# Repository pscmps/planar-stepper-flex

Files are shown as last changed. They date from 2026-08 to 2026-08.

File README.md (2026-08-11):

# Planar Stepper Flex

プリント配線をモータ巻線として使うXY平面ステッパの試作一式です。Pico 2 W、秋月電子の`AE-DRV8835-S` 4個、2種類の2層FPCを対象にしています。

> 現在は非公開で検証中です。回路・FPC・ファームウェアはいずれも試作品で、連続電流定格を保証していません。

## 収録内容

| ディレクトリ | 内容 |
|---|---|
| `hardware/pico2w-drv8835-controller/` | Pico 2 WとDRV8835 4個を載せる制御基板 |
| `hardware/drv8835-driver-module/` | 外部マイコン用DRV8835 4個基板 |
| `hardware/flex-50mm/` | 有効配線領域50 x 50 mmのFPC |
| `hardware/flex-4cards/` | 名刺4枚相当の有効配線領域を持つFPC。手描きシルク入り |
| `firmware/pico2-drv8835/` | USB G-code版、診断版、Pico 2 W Wi-Fi版 |
| `generator/` | 寸法指定可能なFPC生成器と手描きシルク注入処理 |
| `manufacturing/v0.1.0/` | DRC確認済みGerber ZIP、BOM、表裏PNG、ハッシュ |

## 基板プレビュー

| Pico 2 W制御基板 | DRV8835単独基板 |
|---|---|
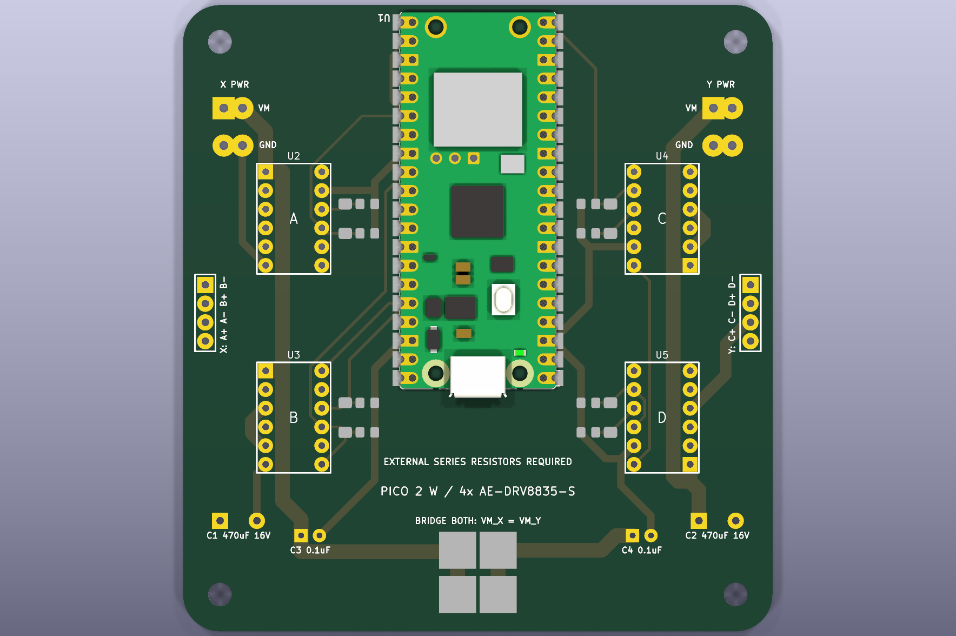
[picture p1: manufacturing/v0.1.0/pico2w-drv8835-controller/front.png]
Pico 2 W制御基板
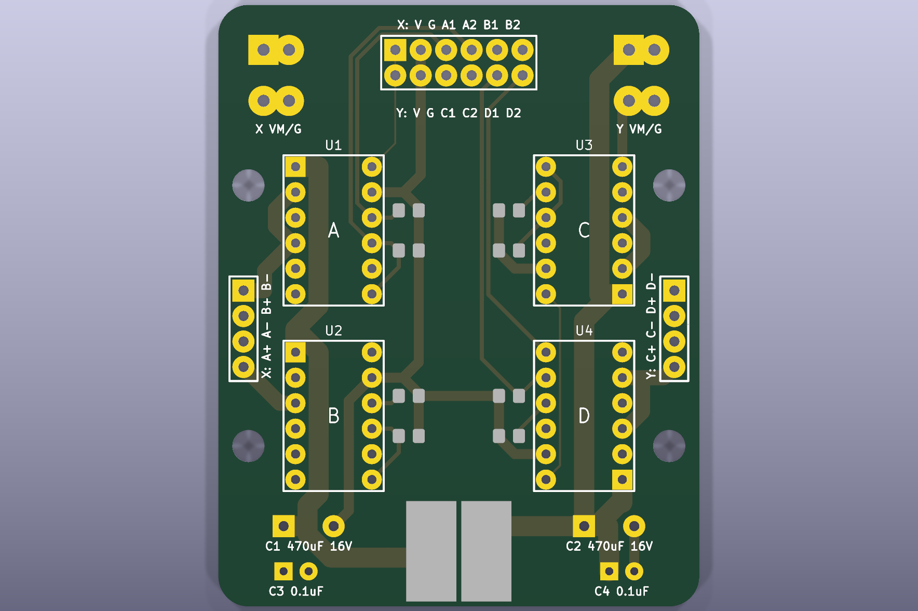
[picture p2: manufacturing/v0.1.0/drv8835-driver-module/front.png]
DRV8835単独基板
|  |  |

| 50 mm FPC | 名刺4枚サイズFPC |
|---|---|
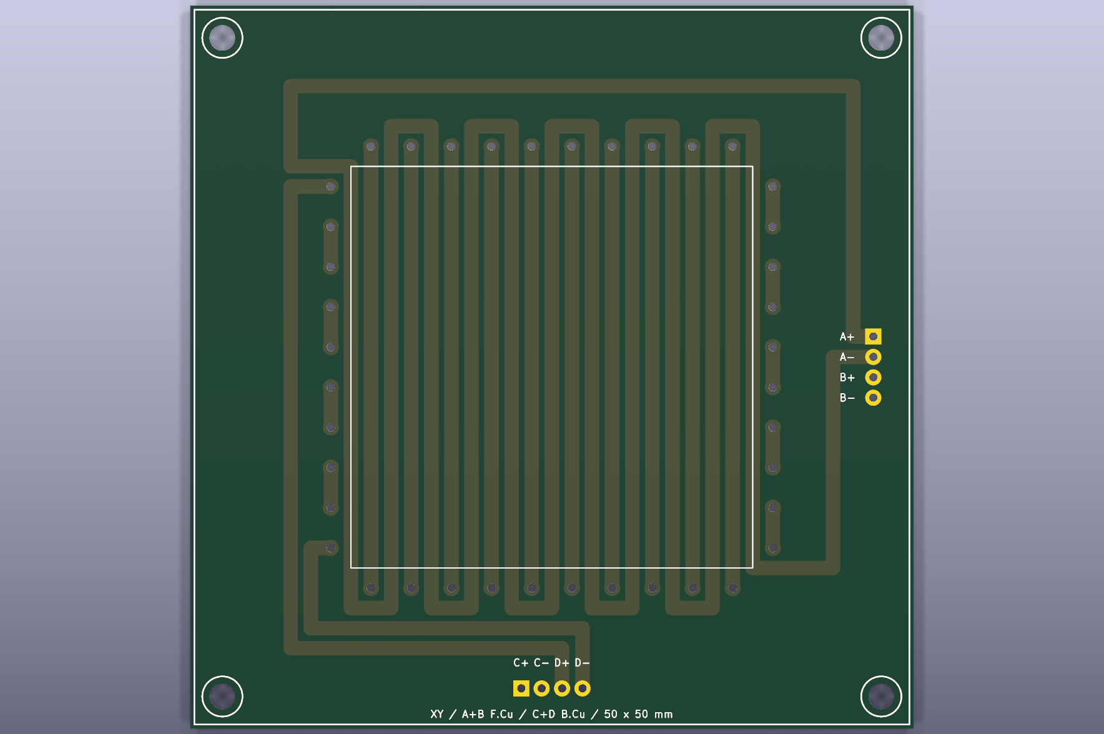
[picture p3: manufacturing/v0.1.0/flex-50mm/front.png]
50 mm FPC
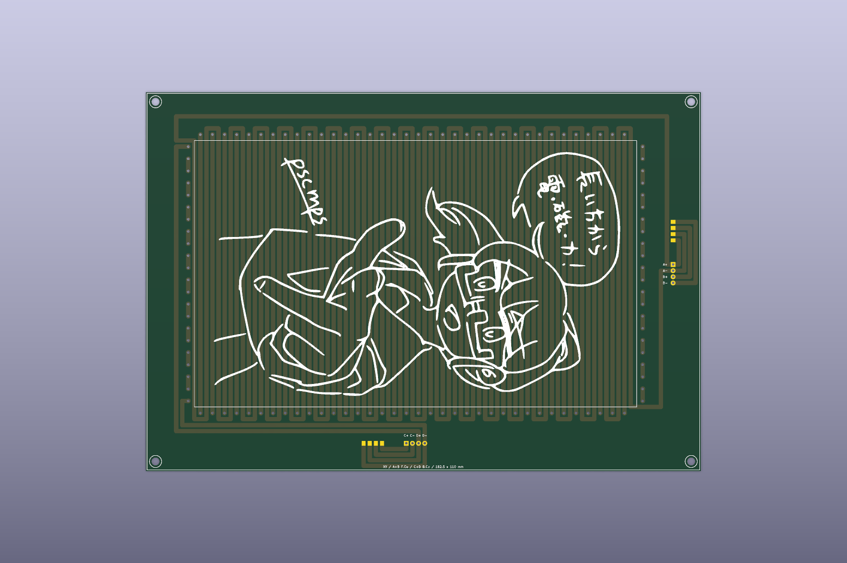
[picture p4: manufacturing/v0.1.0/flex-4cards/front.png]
名刺4枚サイズFPC
|  |  |

背面画像は各`manufacturing/v0.1.0/<board>/back.png`にあります。

## 最短手順

1. [安全上の注意](docs/safety.md)と[配線表](docs/wiring.md)を確認します。
2. VMを切った状態でPicoを起動し、DRV8835入力がLowであることを確認します。
3. 外付け直列抵抗と安定化電源の電流制限を使い、低い電圧・短い励磁から試します。
4. ファームウェアは[ビルド手順](docs/firmware-build.md)に従って生成します。
5. 基板を変更した場合は[製造データ手順](docs/manufacturing.md)でDRCとZIPを再生成します。

FPC生成器の使い方は[基板生成](docs/board-generation.md)、設計元と参考資料は[参考資料](docs/references.md)を参照してください。

## ライセンス

このリポジトリは複数ライセンスです。

| 対象 | ライセンス |
|---|---|
| ハードウェア設計、FPC、KiCadデータ、Gerberなど | [CERN-OHL-P-2.0](LICENSES/CERN-OHL-P-2.0.txt) |
| ファームウェア、生成器、プロジェクト独自ソフトウェア | [MIT](LICENSES/MIT.txt) |
| README、文書、プロジェクト独自の説明画像 | [CC BY 4.0](LICENSES/CC-BY-4.0.txt) |

第三者由来のコード、フットプリント、ライブラリには元のライセンスが適用されます。適用範囲と例外は[ライセンスと権利](RIGHTS.md)、第三者依存は[第三者通知](THIRD_PARTY_NOTICES.md)を参照してください。

## 使用報告は任意です

この設計を使って何か作った場合、作品や写真を教えていただけると嬉しいです。使用報告や連絡は必須ではありません。

If you build, modify, or incorporate this design into a project, the author would be happy to hear about it and see photos of your work. Reporting your use or contacting the author is entirely optional.

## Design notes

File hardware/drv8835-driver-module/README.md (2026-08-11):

# AE-DRV8835-S単独ドライバ基板

外部マイコンからA/B/C/D相を制御する、`AE-DRV8835-S` 4個の2層基板です。

- 外形: 48 x 60 mm、角R3 mm
- 入力J1: 上段X=`VCC GND A1 A2 B1 B2`、下段Y=`VCC GND C1 C2 D1 D2`
- X出力J4: `A+ / A- / B+ / B-`
- Y出力J5: `C+ / C- / D+ / D-`
- 固定穴: φ3.2 mm NPTH 4個

前面

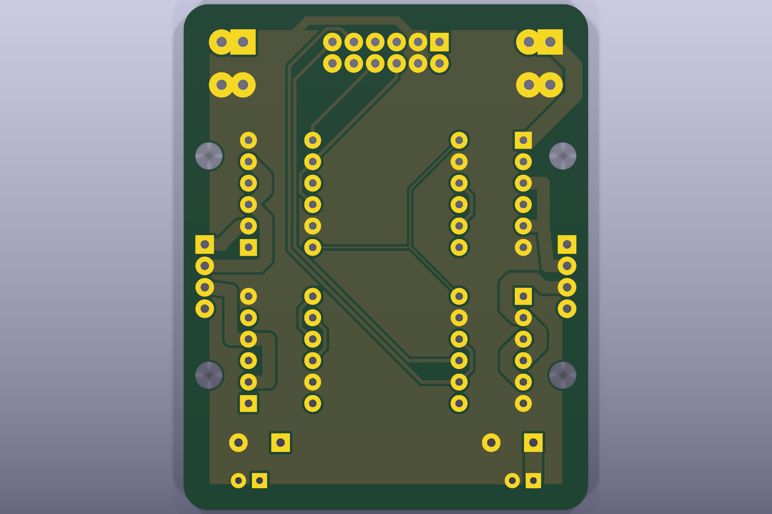
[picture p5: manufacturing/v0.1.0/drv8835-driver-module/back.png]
背面


入力`A1/A2`などはモータ出力名ではなく、対応する相モジュールの`IN1/IN2`です。各入力には10 kohmプルダウンがあります。VM_X/VM_Yは通常分離し、共通化する場合はVMはんだジャンパを両方閉じます。

製造ZIP、BOM、DRCレポートは[`../../manufacturing/v0.1.0/drv8835-driver-module/`](../../manufacturing/v0.1.0/drv8835-driver-module/)にあります。

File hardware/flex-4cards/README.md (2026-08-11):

# 名刺4枚サイズXY平面ステッパーFPC

標準名刺91 x 55 mmを2 x 2で並べた範囲を有効配線領域とする大型2層FPCです。

- 外形: 229.0 x 156.5 mm
- 有効配線領域: 182.5 x 110.0 mm
- ピッチ: 5.0 mm
- B/D相オフセット: 2.5 mm
- 配線幅: 1.8 mm
- 補助SMD端子: 表裏に各4極、既存PTH列から長手方向へ10 mm離して配置
- 手描きシルク: 生成時に`generator/assets/hand-drawn-silkscreen.kicad_mod`から追加

前面

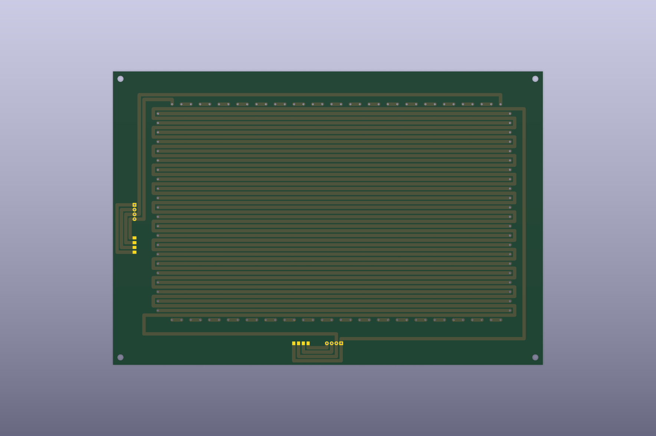
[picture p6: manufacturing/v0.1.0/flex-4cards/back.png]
背面


概算配線長と抵抗はA=4967.5 mm/1.359 ohm、B=4665.1 mm/1.277 ohm、C=4887.5 mm/1.337 ohm、D=4577.6 mm/1.253 ohmです。銅厚35 um、銅抵抗率1.724e-8 ohm mによる一次概算です。

このPCBは直接編集せず、[`../../docs/board-generation.md`](../../docs/board-generation.md)の`--preset 4cards --with-art`で再生成します。製造ZIPは[`../../manufacturing/v0.1.0/flex-4cards/`](../../manufacturing/v0.1.0/flex-4cards/)にあります。

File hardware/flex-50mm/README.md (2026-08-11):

# 50 mm XY平面ステッパーFPC

有効配線領域50 x 50 mmの2層FPCです。A/B相とC/D相を5 mmピッチ、2.5 mmオフセットで交互配置します。

前面

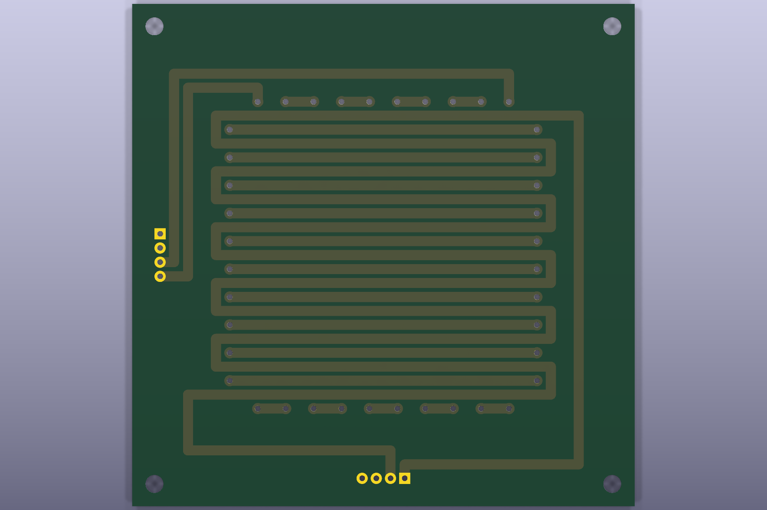
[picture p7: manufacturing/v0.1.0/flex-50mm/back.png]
背面


このPCBは直接編集せず、[`../../docs/board-generation.md`](../../docs/board-generation.md)の`--preset 50mm`で再生成します。製造ZIPは[`../../manufacturing/v0.1.0/flex-50mm/`](../../manufacturing/v0.1.0/flex-50mm/)にあります。

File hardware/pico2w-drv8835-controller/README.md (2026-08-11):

# Pico 2 W + AE-DRV8835-S制御基板

Pico 2 Wと`AE-DRV8835-S` 4個を載せ、A/B/C/D相を個別駆動する2層基板です。

- 外形: 80 x 85 mm、角R5 mm
- 相配線: 1.5 mm
- VM配線: 2.0 mm、X/Y別系統
- モジュール: 2.54 mm、列間7.62 mm、1相につき1個
- X出力: `A+ / A- / B+ / B-`
- Y出力: `C+ / C- / D+ / D-`

前面

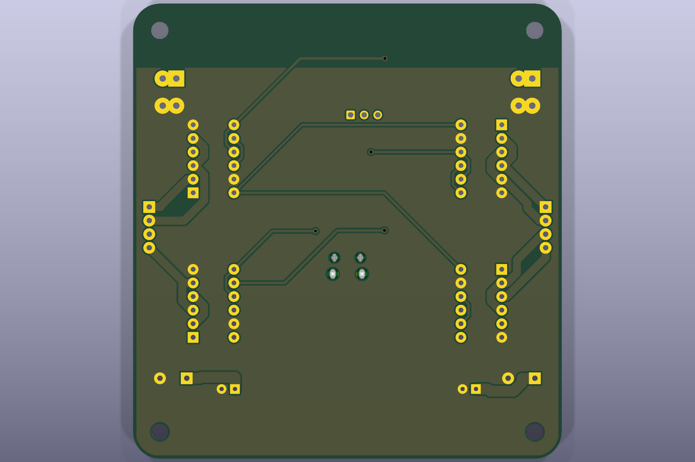
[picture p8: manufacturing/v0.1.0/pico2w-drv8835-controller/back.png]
背面


GPIO、AS5600、サーボ、将来microSDの割当は[`../../docs/wiring.md`](../../docs/wiring.md)を参照してください。VM_X/VM_Yを共通化する場合は両方のVMはんだジャンパを閉じ、電源入力は片側だけを使います。

製造ZIP、BOM、DRCレポートは[`../../manufacturing/v0.1.0/pico2w-drv8835-controller/`](../../manufacturing/v0.1.0/pico2w-drv8835-controller/)にあります。

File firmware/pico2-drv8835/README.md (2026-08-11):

# Pico 2 / Pico 2 W DRV8835 G-codeファームウェア

4個の`AE-DRV8835-S`で平面コイルのA/B/C/D相を駆動し、USBシリアルまたはPico 2 W内蔵Web UIから操作します。TMC2209用ターゲットはこの公開準備リポジトリに含めません。

## ターゲット

| ターゲット | 出力UF2 | 用途 |
|---|---|---|
| `pico2_gcode_drv8835_xy` | `pico2_gcode_drv8835_xy.uf2` | USB G-code通常運転 |
| `pico2_gcode_drv8835_xy_test` | `pico2_gcode_drv8835_xy_test.uf2` | 相単独励磁とGPIO診断 |
| `pico2w_gcode_drv8835_wifi` | `pico2w_gcode_drv8835_wifi.uf2` | USB G-code + Wi-Fi APジョグ |

ビルドはリポジトリ直下の`scripts/build-firmware.ps1`を使います。

## 対応指令

- `G0/G1 X... Y... Z... F...`
- `G2/G3`は未対応。PlotterFlow側で線分化します。
- `G20/G21`、`G90/G91`、`G92`、`G10 L20 P0`
- `$J=G91 G21 X... Y... F...`
- `M17/M18`、`M3/M5`、`M281`、`M980`、`M982`、`M983`
- `?`、`!`、`~`、ジョグキャンセル`0x85`

通常移動は汎用G-codeだけで行います。独自命令は起動時設定と診断に限定します。

## DRV8835設定 M980

```gcode
M18
M980 U8 X60 Y60 I100 J100 H500 C100 B8 R16 A1
M17
```

| 引数 | 意味 |
|---|---|
| `U` | 1フル状態の分割数。`1/2/4/8/16` |
| `X/Y` | X/Y通常PWM、1～100% |
| `I/J` | X/Y初動PWM、1～100% |
| `H` | 移動終了後の保持時間、0～5000 ms |
| `C` | Hi-Z解除時の捕捉時間、0～500 ms |
| `B` | 初動PWMを維持する各軸マイクロステップ数 |
| `R` | 通常PWMへ線形復帰する各軸マイクロステップ数 |
| `A1` | 移動中の軸だけ励磁。`A0`は両軸保持 |

設定後は`G0/G1`と`$J`へ自動適用され、移動ごとに`M980`を送る必要はありません。`B0 R0`は初動ブーストなしの従来動作です。出力OFF、保持終了、新しい軸の励磁開始時にブーストし、保持中の同軸連続G1では再開始しません。

確実な1相励磁を優先する場合は次を使います。

```gcode
M18
M980 U1 X100 Y100 I100 J100 H500 C100 B0 R0 A1
M17
```

## Zサーボ

GP12から50 Hz PWMを出力します。既定はペンアップ1000 us、ペンダウン1800 usです。

```gcode
M281 P0 S1000   ; Up
M281 P1 S1800   ; Down
G0 Z1           ; Up
G0 Z0           ; Down
```

## 任意センサ

- GP26/ADC0: 電流センサ。`M982`で確認。未接続でも運転を継続します。
- AS5600 J1: I2C0、GP8 SDA、GP9 SCL
- AS5600 J2: I2C1、GP10 SDA、GP11 SCL
- `M983`: 1回読出し、`M983 S1/S0`: 状態応答への連続掲載ON/OFF

AS5600が片方または両方なくてもエラー停止しません。詳細な配線は[`../../docs/wiring.md`](../../docs/wiring.md)を参照してください。

## Wi-Fi版

- SSID: `PlanarStepper-XXXX`
- パスワード: `planar-stepper`
- URL: `http://192.168.4.1/`

Pico 2 W自身がAP、DHCP、Web UIを提供します。接続手順とAPIは[`docs/pico2w_wifi_jog.md`](docs/pico2w_wifi_jog.md)にあります。

## 書き込み

BOOTSELを使わず、USBシリアルから同じPicoを特定してpicotoolで再起動・書き込みできます。

```powershell
powershell -ExecutionPolicy Bypass -File tools\flash_wifi.ps1 -Port COM6 -Picotool D:\path\to\picotool.exe -Uf2 D:\path\to\pico2w_gcode_drv8835_wifi.uf2
```

書き込み中はVMとサーボ電源を切ってください。USBデバイスが列挙されない場合はBOOTSEL書き込みが必要です。

## 実機確認

[`docs/drv8835_gcode_bringup.md`](docs/drv8835_gcode_bringup.md)の順に、VM OFFでGPIO Low、低電圧・電流制限、X、Y、XY、停止を確認します。

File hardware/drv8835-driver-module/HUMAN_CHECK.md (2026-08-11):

# 単独ドライバ基板の人間確認手順

1. 外形48 x 60 mm、角R3 mm、φ3.2 mm固定穴4個を確認する。
2. J1上段が`VCC GND A1 A2 B1 B2`、下段が`VCC GND C1 C2 D1 D2`であることを確認する。
3. J4が`A+ A- B+ B-`、J5が`C+ C- D+ D-`であることを確認する。
4. AE-DRV8835-Sの2.54 mmピッチ、列間7.62 mm、向きを実物で確認する。
5. VM_XとVM_Yがジャンパ開放時に絶縁され、GNDは共通であることを確認する。
6. [`../../manufacturing/v0.1.0/drv8835-driver-module/drc.rpt`](../../manufacturing/v0.1.0/drv8835-driver-module/drc.rpt)が違反0、未配線0であることを確認する。
7. VM OFFで全入力のプルダウンと出力端子間の短絡がないことを確認する。
8. 直列抵抗と電流制限を使い、1相ずつ短時間通電する。

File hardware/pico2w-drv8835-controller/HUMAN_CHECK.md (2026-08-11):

# 制御基板の人間確認手順

1. 外形80 x 85 mm、角R5 mm、固定穴、Pico 2 Wと4モジュールの向きを実物へ重ねて確認する。
2. X出力が`A+ A- B+ B-`、Y出力が`C+ C- D+ D-`の順であることを確認する。
3. VM_XとVM_Yがジャンパ開放時に絶縁され、GNDは共通であることをテスターで確認する。
4. VM-GND、3.3V-GND、異なる相出力間に短絡がないことを確認する。
5. 電解コンデンサ、Pico 2 W、AE-DRV8835-Sの向きを確認する。
6. [`../../manufacturing/v0.1.0/pico2w-drv8835-controller/drc.rpt`](../../manufacturing/v0.1.0/pico2w-drv8835-controller/drc.rpt)が違反0、未配線0であることを確認する。
7. 製造業者のGerberビューアで銅箔、マスク、シルク、PTH/NPTHを確認する。
8. VM OFFでPicoを起動し、GP15～GP22と全DRV8835入力がLowであることを確認する。
9. 各相へ直列抵抗を入れ、低電圧・電流制限からX、Yの順に通電する。

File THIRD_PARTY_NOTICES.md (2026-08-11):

# 第三者通知

プロジェクト独自のライセンスは、次の第三者成果物を上書きしません。ソース内の著作権表示とライセンスヘッダーは変更せず維持しています。

## リポジトリへ直接収録しているもの

| 成果物 | 収録場所 | 収録ファイルの著作権・ライセンス | 正式本文と由来 |
|---|---|---|---|
| MicroPython由来DHCP server | `firmware/pico2-drv8835/third_party/pico_examples/dhcpserver.c/.h` | ファイルヘッダーはCopyright (c) 2018-2019 Damien P. George、MIT | pico-examplesの当該ディレクトリに付属するLICENSE（Copyright (c) 2013-2022 Damien P. George）を[LicenseRef-MicroPython-MIT.txt](LICENSES/LicenseRef-MicroPython-MIT.txt)へ原文のまま収録 |
| Raspberry Pi Pico examples DNS server | `firmware/pico2-drv8835/third_party/pico_examples/dnsserver.c/.h` | ファイルヘッダーはCopyright (c) 2022 Raspberry Pi (Trading) Ltd.、`BSD-3-Clause` | pico-examplesルートのLICENSE.TXT（Copyright 2020 (c) 2020 Raspberry Pi (Trading) Ltd.）を[BSD-3-Clause.txt](LICENSES/BSD-3-Clause.txt)へ原文のまま収録 |
| KiCad公式Pico Wフットプリント | `hardware/pico2w-drv8835-controller/footprints/official-kicad/` | KiCad library contributors、CC BY-SA 4.0とKiCad libraries exception | KiCad公式`LICENSE.md`を[LicenseRef-KiCad-Libraries.txt](LICENSES/LicenseRef-KiCad-Libraries.txt)へ原文のまま収録 |

DHCP/DNSの派生元は、Raspberry Pi公式pico-examplesのコミット`eed0c298202ddbdc3aadb386abedb71ae528e5fb`です。DHCP付属LICENSEはコミット`1c5d9aa567598e6e3eadf6d7f2d8a9342b44dab4`、pico-examplesルートLICENSE.TXTはコミット`46078742c7f8dea8b5a0998c73b38ff970fb1b64`の原文を確認しました。収録DHCPコードには再接続時の要求IP補完、ホスト名・送受信診断ログ、初期化結果の返却を追加しています。DNSコードの差分は未使用引数警告の抑制です。元の著作権・ライセンスヘッダーは変更していません。

`BSD-3-Clause.txt`とPico SDK付属LICENSEの冒頭にある`Copyright 2020 (c) 2020 Raspberry Pi (Trading) Ltd.`は、年が重複して見えますがRaspberry Pi公式原文の表記です。このリポジトリでは訂正せず、一字一句そのまま収録しています。

KiCadフットプリントは、公式コミット`18227ee1af2680cab46c6ed908dd53e9272a6116`の同名ファイルと比較し、2個のkeep-out zoneから`F.Paste`と`B.Paste`を除いた差分だけであることを確認しました。詳細は同ディレクトリの`NOTICE`を参照してください。

KiCadフットプリントの形状はRaspberry Pi Pico W/Pico 2 W公式寸法資料を参照しています。Raspberry Piの名称、商標、データシート、製品設計に対する権利は各権利者に帰属し、このリポジトリのライセンス対象ではありません。

## ビルド依存と配布UF2

次の依存物はリポジトリへソースを複製していませんが、Pico SDKを通してファームウェアのビルドまたは配布UF2へ組み込まれます。

| 依存物 | 確認したリビジョン | 著作権・ライセンス | 依存元から複製した本文 |
|---|---|---|---|
| Raspberry Pi Pico SDK | `a1438dff1d38bd9c65dbd693f0e5db4b9ae91779` | Copyright 2020 (c) 2020 Raspberry Pi (Trading) Ltd.、BSD-3-Clause | [LicenseRef-Raspberry-Pi-Pico-SDK-BSD-3-Clause.txt](LICENSES/LicenseRef-Raspberry-Pi-Pico-SDK-BSD-3-Clause.txt) |
| lwIP | `77dcd25a72509eb83f72b033d219b1d40cd8eb95` | Copyright (c) 2001, 2002 Swedish Institute of Computer Science、BSD系3条項 | [LicenseRef-lwIP-BSD-3-Clause.txt](LICENSES/LicenseRef-lwIP-BSD-3-Clause.txt) |
| TinyUSB | `86ad6e56c1700e85f1c5678607a762cfe3aa2f47` | Copyright (c) 2018, hathach (tinyusb.org)、MIT | [LicenseRef-TinyUSB-MIT.txt](LICENSES/LicenseRef-TinyUSB-MIT.txt) |
| cyw43-driver | `dd7568229f3bf7a37737b9e1ef250c26efe75b23` | Copyright (C) 2019-2022 George Robotics Pty Ltd、Raspberry Pi製半導体との組み合わせに限定した許諾 | [LicenseRef-CYW43-Raspberry-Pi.txt](LICENSES/LicenseRef-CYW43-Raspberry-Pi.txt) |

`manufacturing/v0.1.0/firmware/`のUF2を再配布する場合も、この第三者通知と該当ライセンス本文を一緒に提供してください。実際にリンクされるコンポーネントはPico SDKのバージョンとCMake設定に依存します。特にWi-Fi版UF2の`cyw43-driver`は、Pico 2 Wを含むRaspberry Pi Ltd製半導体と組み合わせて使用・再配布する場合に限られます。

## KiCad標準ライブラリを使った設計

KiCad標準ライブラリはCC BY-SA 4.0にKiCad libraries exceptionを加えた条件です。この例外は、ライブラリデータを使って作成した回路・基板設計や生成ファイルを別ライセンスで提供することを認めています。そのため、このプロジェクト独自の基板設計とGerberにはCERN-OHL-P-2.0を適用します。再配布するKiCadライブラリ要素そのものには元のライセンスを維持します。

## 外部リンク

READMEや`docs/references.md`から参照する外部記事、データシート、Webサイトの内容や画像は、このリポジトリのライセンス対象ではありません。現時点で第三者記事の画像や本文はリポジトリへ転載していません。

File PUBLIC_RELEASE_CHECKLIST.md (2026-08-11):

# 公開前チェックリスト

- [x] ハードウェアを`CERN-OHL-P-2.0`に決定した
- [x] プロジェクト独自ソフトウェアを`MIT`に決定した
- [x] プロジェクト独自文書・画像を`CC-BY-4.0`に決定した
- [x] `LICENSES/`へ正式本文と第三者ライセンス通知を収録した
- [x] `LICENSES/`からSPDXテンプレート変数と未展開プレースホルダーを除去した
- [x] Pico SDK、lwIP、TinyUSB、cyw43-driver、pico-examples、KiCadの実依存元と本文を照合した
- [x] `REUSE.toml`と`RIGHTS.md`へ適用範囲と例外を記載した
- [x] 第三者ソースの著作権・ライセンスヘッダーを維持した
- [ ] リポジトリをprivateのまま最終レビューした
- [ ] 個人情報、Wi-Fi資格情報、Webhook、絶対パスを除去した
- [ ] 4基板のDRCが違反0、未配線0であることを再確認した
- [ ] Gerber ZIPとUF2のSHA-256を再検証した
- [ ] BOMと実装品の型番・向きを照合した
- [ ] 実機の電流制限、発熱、サーボ方向、非常停止を再確認した
- [ ] READMEの画像とリンクをGitHub上で確認した
- [ ] privateからpublicへ変更する直前のコミットへタグを付けた
- [ ] GitHubのvisibilityをpublicへ変更した

使用報告は任意です。公開条件やライセンス条件として要求しません。

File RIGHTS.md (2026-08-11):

# ライセンスと権利

Planar Stepper Flexは、成果物の種類に応じた複数ライセンスで提供します。Copyright (c) 2026 pscmps.

## ハードウェア設計

プロジェクト独自のハードウェア設計は[CERN Open Hardware Licence Version 2 - Permissive](LICENSES/CERN-OHL-P-2.0.txt)、SPDX識別子`CERN-OHL-P-2.0`で提供します。

対象:

- `hardware/`以下の`.kicad_pcb`、`.kicad_pro`、配線マニフェスト、BOMなどの設計データ
- `generator/assets/hand-drawn-silkscreen.kicad_mod`
- FPC、回路、PCB、Gerber、ドリル、製造ZIPなど、それらから生成されたハードウェア設計データ

製造、改造、再配布、商用利用が可能です。CERN-OHL-P-2.0はpermissive版であり、改造設計を同じライセンスで公開することを要求しません。ただし、ライセンス本文が定めるNotice保持、変更表示、製品受領者からNoticeへアクセスできる状態などの条件は守ってください。

## ソフトウェア

プロジェクト独自のソフトウェアは[MIT License](LICENSES/MIT.txt)、SPDX識別子`MIT`で提供します。

対象:

- `firmware/`のプロジェクト独自ソース、Web UI、ツール、テスト、G-code例
- `generator/`のPythonコード。ただしハードウェア設計アセットは前項
- `hardware/`内の基板生成・自動配線Pythonスクリプト
- `scripts/`とその他のプロジェクト独自ソフトウェア

`firmware/pico2-drv8835/third_party/`などの第三者コードには元のライセンスが適用され、プロジェクトのMIT Licenseで上書きしません。UF2はプロジェクト独自MITコードと第三者コンポーネントを含む複合物です。

## 文書と画像

プロジェクト独自の文書と説明画像は[Creative Commons Attribution 4.0 International](LICENSES/CC-BY-4.0.txt)、SPDX識別子`CC-BY-4.0`で提供します。

対象:

- `README.md`、`AGENTS.md`、`PUBLIC_RELEASE_CHECKLIST.md`、`docs/`
- 各サブディレクトリのREADME、確認手順、説明文書
- プロジェクトで新規作成したPNG、SVG、基板プレビュー、説明図

推奨する表示例は「Planar Stepper Flex by pscmps, CC BY 4.0, https://github.com/pscmps/planar-stepper-flex」です。これはCC BY 4.0の表示を分かりやすくする例であり、ライセンスが要求する範囲を超える追加条件ではありません。

## 第三者成果物と例外

第三者由来のコード、ライブラリ、フットプリント、資料、画像、商標には上記のプロジェクトライセンスを適用しません。[第三者通知](THIRD_PARTY_NOTICES.md)と各ソース内の著作権・SPDXヘッダーを優先してください。

特に、KiCad公式ライブラリ由来フットプリントはCC BY-SA 4.0とKiCad libraries exceptionの組み合わせです。KiCadの例外により、そのライブラリ要素を使って作成した基板設計と生成ファイルへCERN-OHL-P-2.0を適用できますが、収録したフットプリント単体はKiCad側の条件を維持します。`REUSE.toml`では、この組み合わせを`LicenseRef-KiCad-Libraries`として表します。

Pico 2 W Wi-Fi版UF2に含まれる`cyw43-driver`は`LicenseRef-CYW43-Raspberry-Pi`です。Raspberry Pi Ltd製のRP2040、RP2350その他同社製半導体との組み合わせに限定して利用・再配布できます。この制約はWi-Fiバイナリ内の第三者部分に由来し、プロジェクト独自ソースのMIT Licenseを変更するものではありません。

正式な対応表は[`REUSE.toml`](REUSE.toml)にも記載しています。第三者ファイルを含め、対象ごとの情報を`precedence = "override"`で一意にしています。ソース内の著作権・ライセンス表示も維持しています。

## ライセンス本文の出典

- `CERN-OHL-P-2.0.txt`: Open Hardware Repositoryが配布する`cern_ohl_p_v2.txt`の原文
- `CC-BY-4.0.txt`: Creative Commons公式`https://creativecommons.org/licenses/by/4.0/legalcode.txt`の原文
- `MIT.txt`: 標準MIT本文へ、このプロジェクトの実際の表示`Copyright (c) 2026 pscmps`を記載
- 第三者ライセンス: [第三者通知](THIRD_PARTY_NOTICES.md)に記録した各依存元の付属ファイルから複製

`LICENSES/`にはSPDXテンプレート用の`<<var;...>>`、`<<beginOptional...>>`、`<year>`などを含めません。監査済み原文の改変とプレースホルダー再混入は`scripts/check-license-scope.py`で検出します。

## 使用報告

この設計を使って何か作った場合、作品や写真を教えていただけると嬉しいです。使用報告や連絡は必須ではありません。

If you build, modify, or incorporate this design into a project, the author would be happy to hear about it and see photos of your work. Reporting your use or contacting the author is entirely optional.

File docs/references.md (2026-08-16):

# 参考資料

- [Research log: PCB stepper motor](https://kevinlynagh.com/pcb-stepper/)
- [Hackaday: The Two-Dimensional Stepper Motor](https://hackaday.com/2019/05/09/the-two-dimensional-stepper-motor/)
- [Hackaday.io: 2D Stepper Motor Etched on PCB](https://hackaday.io/project/164507-2d-stepper-motor-etched-on-pcb-micro-manipulator)
- [秋月電子 AE-DRV8835-S商品ページ](https://akizukidenshi.com/catalog/g/g109848/)
- [秋月電子 AE-DRV8835-S説明書](https://akizukidenshi.com/goodsaffix/AE-DRV8835-S_20210526.pdf)
- [TI DRV8835データシート](https://www.ti.com/lit/ds/symlink/drv8835.pdf)
- [Raspberry Pi Pico 2 Wデータシート](https://datasheets.raspberrypi.com/picow/pico-2-w-datasheet.pdf)
- [Raspberry Pi Pico SDK](https://github.com/raspberrypi/pico-sdk)
- [KiCad 10 Documentation](https://docs.kicad.org/10.0/)
- [PlotterFlow Web](https://pscmps.github.io/plotterflow-web/)
- [PlotterFlow GitHub](https://github.com/pscmps/plotterflow-web)

参考設計と同じ性能や安全性を保証するものではありません。寸法、材料、駆動方式の差を考慮して評価してください。

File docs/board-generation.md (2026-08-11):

# FPC基板生成

## プリセット生成

KiCad 10付属Pythonを使います。

```powershell
D:\kicad10\bin\python.exe generator\generate_flex_board.py --preset 50mm --output hardware\flex-50mm\one_axis_stepper.kicad_pcb
D:\kicad10\bin\python.exe generator\generate_flex_board.py --preset 4cards --with-art --output hardware\flex-4cards\planar_stepper_flex_4cards.kicad_pcb
```

`--with-art`は名刺4枚プリセットへだけ指定できます。手描きシルクは`generator/assets/hand-drawn-silkscreen.kicad_mod`から注入されます。

## 任意寸法

```powershell
D:\kicad10\bin\python.exe generator\generate_flex_board.py --preset 50mm --active-width 100 --active-height 80 --output build\flex-100x80.kicad_pcb
```

有効配線領域を指定し、外形を省略した場合は折り返しと端子用に各方向40 mmを加えます。必要に応じて`--board-width`、`--board-height`、`--pitch`、`--trace-width`、`--spacing`、`--phase-offset`を指定できます。全オプションは`--help`で確認してください。

## 検証

```powershell
python -m unittest discover -s generator\tests -v
```

生成後は必ず`kicad-cli pcb drc`を実行してください。製造データまで一括生成する場合は`docs/manufacturing.md`を参照します。

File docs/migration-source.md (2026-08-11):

# 移行元

このリポジトリは`pscmps/kicad-10-one-axis-planar-stepper`から、公開対象をDRV8835方式へ限定して再構成しました。

- 取り込み基準コミット: `2f0866f`
- 名刺4枚版FPC: 移行時点の未コミット作業ツリーにあった手描きシルクと追加端子を含む版
- 移行後に再生成した名刺4枚版PCB SHA-256: `b0611244fdda0f6ffc602114e7ef7fc088943e93047a177f7a169f11e8145e2e`
- 除外: TMC2209、コイルマトリクス、M5Stack、Fusion治具、実験ログ

移行元リポジトリは変更していません。過去の検討履歴は移行元のGit履歴を参照してください。

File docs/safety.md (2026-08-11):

# 安全上の注意

- DRV8835にはTMC2209のような相電流設定機能がありません。直列抵抗、電源電流制限、PWM dutyで電流を制限します。
- 初回はVMを低くし、各相へ1.5 ohm・5 W以上の直列抵抗を入れ、短時間だけ励磁します。
- FPC配線は低抵抗です。電源を直接つなぐと過電流、発熱、銅箔損傷の危険があります。
- 初動ブースト100%は連続運転用ではありません。抵抗、DRV8835、コネクタ、FPCの温度を確認します。
- VM-GND間へ電解コンデンサを配置し、極性と耐圧を確認します。
- 配線変更、導通測定、Pico書き込みはVMとサーボ電源を切って行います。
- `M18`、停止、キャンセル後に8出力がLowとなることをVM投入前に確認します。
- 製造した基板は最初に電流制限付き安定化電源で確認し、無人運転しないでください。

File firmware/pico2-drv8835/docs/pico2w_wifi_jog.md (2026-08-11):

# Pico 2 W スマホWi-Fiジョグ手順

## 対象と制約

`pico2w_gcode_drv8835_wifi.uf2`は、Pico 2 W自身をWi-Fiアクセスポイントにして、スマホのブラウザからDRV8835版XY平面ステッパをジョグするファームです。既存のUSB G-codeと`M980`は残しています。

この機能は操作経路だけを追加します。現在検討中の電源容量、直列抵抗、コイル電流、磁力の問題は改善しません。実機試験では従来どおりVM 3 V、電源制限1.5 A、各相1.5 Ωから開始してください。

## GPIO配置

Wi-Fi版もUSB版DRV8835バックエンドと同じGPIOを使用します。起動処理の最初にGP15からGP22を出力Lowへ設定し、Wi-Fi初期化に失敗しても励磁しません。

| 軸・相 | DRV8835入力 | Pico 2 W GPIO |
|---|---|---:|
| X A相 | AIN1 / AIN2 | GP19 / GP20 |
| X B相 | BIN1 / BIN2 | GP21 / GP22 |
| Y C相 | AIN1 / AIN2 | GP15 / GP16 |
| Y D相 | BIN1 / BIN2 | GP17 / GP18 |
| Zサーボ | PWM信号 | GP12（物理16番） |

Pico 2 W、DRV8835、モーター電源、サーボ電源のGNDを共通にします。VMやサーボ電源をPico 2 Wの3V3端子から供給しないでください。サーボは外部5 Vから給電します。

## 接続

1. VMをOFFにしてPico 2 Wを起動します。
2. USBシリアルの起動ログで`WIFI AP`、SSID、URLを確認します。
3. スマホのWi-Fi設定で`PlanarStepper-XXXX`を選びます。
4. パスワード`planar-stepper`を入力します。
5. インターネット未接続の警告が出ても、このWi-Fi接続を維持します。
6. ブラウザで`http://192.168.4.1/`を開きます。

Pico自身のAP専用です。DNSと主要OSの接続確認URLに応答するため、対応端末では操作画面が自動表示されます。家庭内Wi-Fiへの参加、設定保存、インターネット中継は実装していません。

## 画面操作

| ボタン | G-code方向 |
|---|---|
| 上 | Yマイナス |
| 下 | Yプラス |
| 左 | Xプラス |
| 右 | Xマイナス |
| 中央の停止 | 移動キャンセル後、全出力Low |
| ペン上 | `G0 Z1`相当 |
| ペン下 | `G1 Z0`相当 |

駆動モードは、1相を100%励磁する「確実動作 U1」と、2相をsin/cos PWMする「滑らか動作 U8（実験）」から選択できます。既定は確実動作で、移動量は2.5 mmです。滑らか動作へ切り替えると0.625 mmを選択します。移動量は`0.3125 / 0.625 / 2.5 / 10 mm`から変更でき、Feedは30から1000 mm/min、初期値は300 mm/minです。

HTTP要求は1件だけキューへ入り、メインループで既存の`$J=G91 G21 ...`に変換されます。実行中は十字ボタンを無効にし、重複ジョグを受け付けません。中央停止は通信コールバックからプランナのキャンセルフラグを立て、移動ループが約1 ms周期で検出します。

## 内部API

```text
GET /api/jog.cgi?axis=X&direction=1&distance=0.625&feed=300
GET /api/stop.cgi
GET /api/mode.cgi?activeOnly=1&microsteps=1&captureMs=100
GET /api/pen.cgi?state=up
GET /api/pen.cgi?state=down
GET /api/status.shtml
```

`axis`は`X`または`Y`、`direction`は`-1`または`1`、移動量は画面にある4値だけ、Feedは30から1000の整数だけを受理します。不正入力はHTTP 400、実行中の追加要求は`busy`を返します。
`pen.cgi`は`state=up`または`state=down`だけを受理し、メインループで通常のZ G-codeへ変換します。

状態応答例:

```json
{"ready":true,"busy":false,"armed":true,"outputs":false,"activeOnly":true,"microsteps":1,"captureMs":100,"activeMask":0,"xAngle":0,"yAngle":0,"xPhase":"A+","yPhase":"C+","clients":1,"x":0.0000,"y":0.0000,"z":1.0000,"penPulseUs":1000,"penUp":true,"lastResult":"ok"}
```

`activeOnly=1`は移動する軸だけを励磁し、`activeOnly=0`は常にXY両軸を励磁します。`microsteps`は画面で使用する`1`または`8`、`captureMs`はHi-Z解除時と対象軸切替時の捕捉時間で、0から500msです。設定変更時は安全のため一度全出力をLowへ戻し、論理座標を維持したまま電気角を基準相へ同期します。

## 接続できない場合の判定

USBシリアルを115200 baudで開いたまま、スマホ側でネットワークを一度削除してから再接続します。

- `[WIFI AP: clients=0]`のまま: パスワード認証またはWi-Fi関連付けまで到達していません。
- `[WIFI AP: clients=1]`は出るが`DHCPS: client connected`が出ない: DHCP払い出し段階の問題です。
- `DHCPS: client connected`まで出る: IP取得済みです。ブラウザへ`http://192.168.4.1/`を直接入力します。

ファーム0.6.2以降は、スマホの初回DHCP要求だけでなく、要求IPオプションを省略する再接続・リース更新も受理します。インターネット未接続の警告では「このネットワークを使用」を選びます。IP取得済みなのに携帯回線へ迂回する場合だけ、確認中はモバイルデータ通信を一時的にOFFにします。

## 安全な実機確認

1. VMをOFFにし、起動直後からGP15からGP22がLowであることを確認します。
2. スマホからAPと操作画面を開き、座標と`出力 Hi-Z`が表示されることを確認します。
3. 十字ボタンを連打し、実行中に2件目が入らないことを確認します。
4. VM 3 V、電流制限1.5 A、各相1.5 Ωで、「確実動作 U1」、移動量2.5 mmからYを試します。
5. 次にX、最後にXYを交互に操作します。
6. 10 mmの低速ジョグ中に中央停止を押し、200 ms以内に停止して出力がLowへ戻ることを確認します。
7. 移動中にブラウザを閉じます。指定距離以上に継続せず、移動完了500 ms後に`出力 Hi-Z`になることを確認します。
8. USBから`M122`を送り、座標、armed状態、`single-phase`、`capture_ms=100`、現在相、対象軸、出力状態を照合します。

標準G-codeでの比較には次を使用します。

```gcode
M18
M980 U1 X100 Y100 H500 A1 C100
M17
G91
G1 X2.5 F300
G1 X-2.5 F300
G1 Y2.5 F300
G1 Y-2.5 F300
M18
```

回路の発熱、電源CC移行、異音、抵抗の過熱を検出した場合は、画面操作を続けずVMをOFFにします。

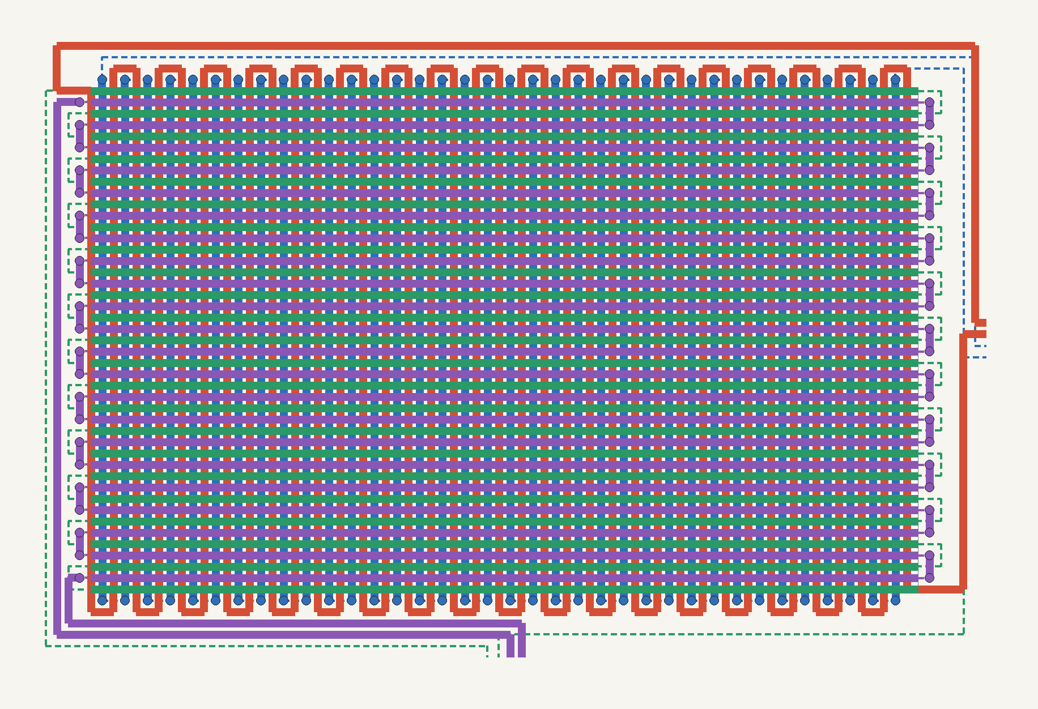
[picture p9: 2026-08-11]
hardware/flex-4cards/planar_stepper_flex_4cards_overlay.png

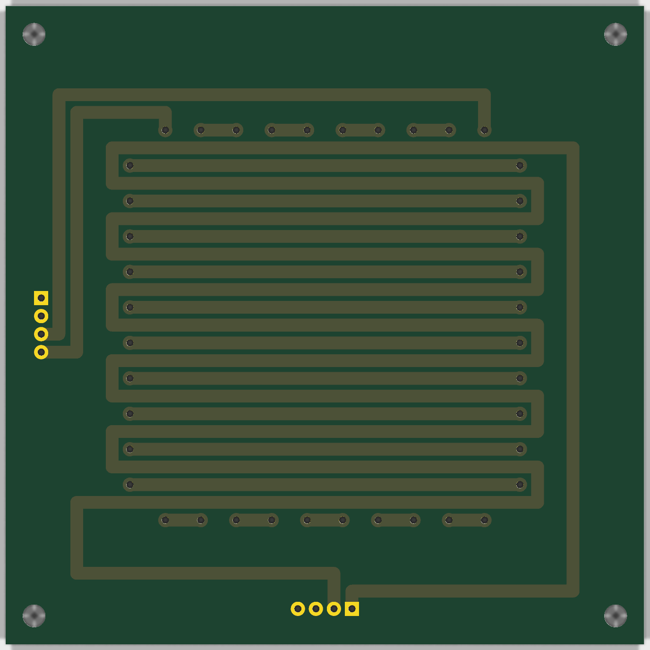
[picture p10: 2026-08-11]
hardware/flex-50mm/one_axis_stepper_bottom.png

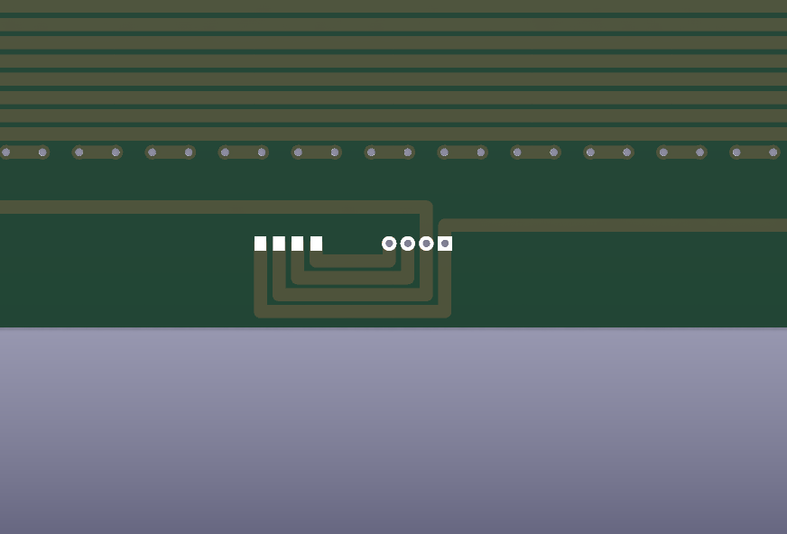
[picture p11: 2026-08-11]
hardware/flex-4cards/terminal_j2_back.png

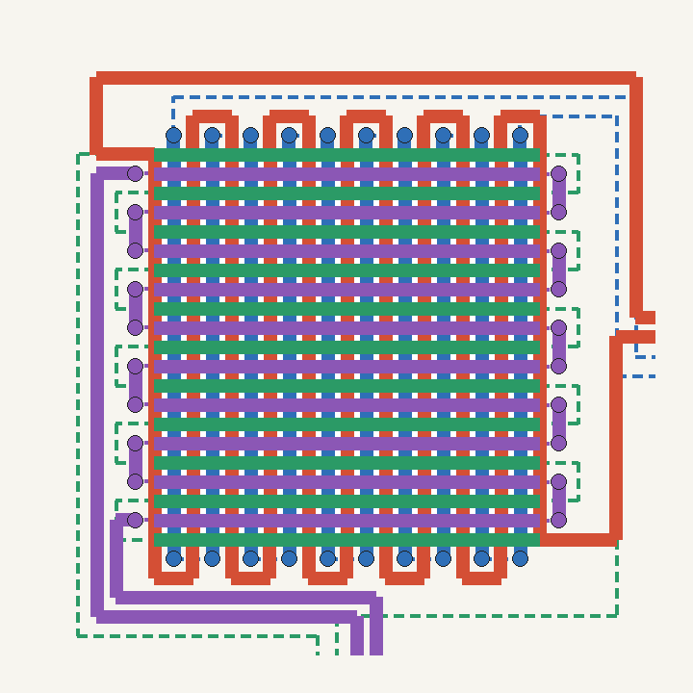
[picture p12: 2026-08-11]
hardware/flex-50mm/one_axis_stepper_single_layer_preview.png

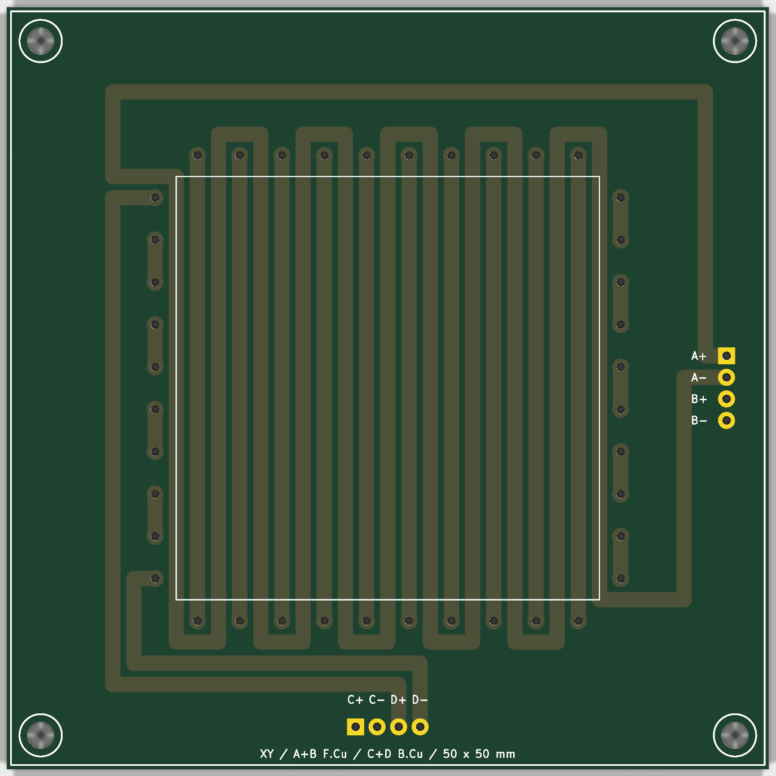
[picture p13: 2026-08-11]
hardware/flex-50mm/one_axis_stepper.png

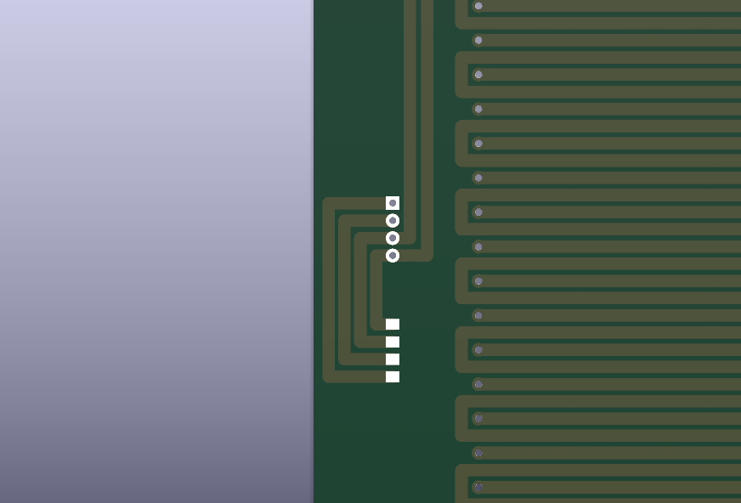
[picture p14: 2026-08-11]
hardware/flex-4cards/terminal_j1_back.png

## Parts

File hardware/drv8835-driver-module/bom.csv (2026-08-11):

参照 | 値 | 数量 | 備考
U1-U4 | 秋月電子 AE-DRV8835-S | 4 | 各相に1モジュール・内部2ブリッジ並列
SOCKET-U1-U4 | 1x6 ピンソケット P2.54mm | 8 | モジュール1個につき2本
R1-R8 | 10k ohm 0805 | 8 | 入力プルダウン
C1-C2 | 470uF 16V ラジアル P5.00mm | 2 | 極性注意
C3-C4 | 0.1uF セラミック P2.50mm | 2 | 各軸VMバイパス
J1 | 2x6 ピンソケット P2.54mm | 1 | 外部マイコン入力
J2-J3 | 1x2 ピンソケット P2.54mm | 4 | 各軸のVM/GNDに2本ずつ・1接点3A以上
J4-J5 | 1x4 ピンソケット P2.54mm | 2 | モータ出力・1接点3A以上
SJ1-SJ2 | 半田ジャンパ | 2 | VM_X/VM_Y共通化時だけ両方を短絡
H1-H4 | M3ねじ・スペーサー | 4 | 基板穴径3.2mm・NPTH
EXT-R-A-D | 1.5 ohm 5W 抵抗 | 4 | 初回電流制限用・基板外へ直列接続

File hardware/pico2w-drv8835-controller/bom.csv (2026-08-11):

参照 | 値 | 数量 | 備考
U1 | Raspberry Pi Pico 2 W | 1 | KiCad公式Pico W SMDフットプリントを使用して直接実装
U2-U5 | 秋月電子 AE-DRV8835-S | 4 | 各相に1モジュールを使用し内部2ブリッジを並列接続
SOCKET-U2-U5 | 1x6 ピンソケット P2.54mm | 8 | DRV8835モジュール1個につき2本
R1-R8 | 10k ohm 0805 | 8 | GPIOプルダウン
C1-C2 | 470uF 16V ラジアル P5.00mm | 2 | 極性注意
C3-C4 | 0.1uF セラミック P2.50mm | 2 | 各軸VMバイパス
J1-J2 | 1x2 ピンソケット P2.54mm | 4 | 各軸2列でVM-GND列間5.08mm・1接点3A以上
J3-J4 | 1x4 ピンソケット P2.54mm | 2 | 1接点3A以上
SJ1-SJ2 | 半田ジャンパ | 2 | 通常開放・VM_X/VM_Y間0.5mm・共通化時は両方を半田ブリッジ
H1-H4 | M3ねじ・スペーサー | 4 | 基板穴径3.2mm
EXT-R-A-D | 1.5 ohm 5W 抵抗 | 4 | 初回電流制限用の外付け抵抗・基板には実装しない

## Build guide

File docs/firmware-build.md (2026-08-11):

# ファームウェアのビルド

Pico SDK環境をDドライブへ用意し、リポジトリ直下で実行します。

```powershell
. D:\dev\pico2-tmc2209\env.ps1
powershell -ExecutionPolicy Bypass -File scripts\build-firmware.ps1
```

生成ターゲット:

| UF2 | 用途 |
|---|---|
| `pico2_gcode_drv8835_xy.uf2` | Pico 2/Pico 2 WのUSB G-code運転 |
| `pico2_gcode_drv8835_xy_test.uf2` | GPIOと相励磁の診断 |
| `pico2w_gcode_drv8835_wifi.uf2` | Pico 2 WのUSB + Wi-Fi APジョグ |

ホスト単体テストも同じスクリプトで実行します。書き込みとG-code仕様は[ファームウェアREADME](../firmware/pico2-drv8835/README.md)を参照してください。

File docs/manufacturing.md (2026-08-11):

# 製造データ

`scripts/build-all.ps1`はFPCを再生成し、単体テスト、4基板のDRC、表裏PNG、Gerber、ドリル、ZIP、SHA-256をまとめて更新します。

```powershell
powershell -ExecutionPolicy Bypass -File scripts\build-all.ps1 `
  -KicadCli D:\kicad10\bin\kicad-cli.exe `
  -KicadPython D:\kicad10\bin\python.exe
```

DRC違反または未配線が1件でもある場合、ZIP生成は失敗します。成果物は`manufacturing/v0.1.0/`へ出力されます。

Gerber ZIPは機械的に生成済みでも、そのまま発注可能という保証ではありません。FPCの銅厚、基材厚、補強板、カバーレイ、最小曲げ半径と、制御基板の部品向き・穴径を製造業者のプレビューで確認してください。

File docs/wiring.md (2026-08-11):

# 配線表

## Pico 2 W GPIO

| 用途 | GPIO | 物理ピン | 備考 |
|---|---|---:|---|
| X A相 IN1 / IN2 | GP19 / GP20 | 25 / 26 | DRV8835 U2 |
| X B相 IN1 / IN2 | GP21 / GP22 | 27 / 29 | DRV8835 U3 |
| Y C相 IN1 / IN2 | GP15 / GP16 | 20 / 21 | DRV8835 U4 |
| Y D相 IN1 / IN2 | GP17 / GP18 | 22 / 24 | DRV8835 U5 |
| ZサーボPWM | GP12 | 16 | 50 Hz、既定はUp=1000 us、Down=1800 us |
| 電流センサ入力 | GP26 / ADC0 | 31 | 任意。未接続でも運転継続 |
| AS5600 J1 | GP8 SDA / GP9 SCL | 11 / 12 | I2C0、任意 |
| AS5600 J2 | GP10 SDA / GP11 SCL | 14 / 15 | I2C1、任意 |
| 将来microSD | GP2 SCK / GP3 MOSI / GP4 MISO / GP5 CS | 4 / 5 / 6 / 7 | 現ファームでは未使用 |

AS5600は3.3 Vで使用し、`DIR`は初回GND、`OUT`と`PGO`は未接続とします。センサがない場合もエラー停止しません。

## コイル出力

| 軸 | コネクタ順 |
|---|---|
| X | `A+ / A- / B+ / B-` |
| Y | `C+ / C- / D+ / D-` |

X/YのGNDは共通です。`VM_X`と`VM_Y`は通常分離し、同じ電源を使う場合だけ基板上のVMはんだジャンパを両方閉じます。ジャンパを閉じた状態で別々の電源を接続しないでください。

## AE-DRV8835-S

各相につき1モジュールを使い、A/Bの2ブリッジを並列にします。`MODE=GND`のIN/INモード、`VCC=3.3 V`、GND共通です。モジュールの詳細なピン順は秋月電子の説明書を参照してください。

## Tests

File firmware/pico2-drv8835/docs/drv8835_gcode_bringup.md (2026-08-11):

# Pico 2とDRV8835による標準G-code運転手順

## 対象

この手順はRaspberry Pi Pico 2 WH/Pico 2 W、秋月電子AE-DRV8835-S 4個、XY平面モータ基板を
`pico2_gcode_drv8835_xy.uf2`または`pico2w_gcode_drv8835_wifi.uf2`で動かす場合を対象にします。
診断用の`M974`から`M978`は通常運転では使用しません。

## 配線

各相には実機で動作を確認した1.5Ω、5W以上の直列抵抗を入れます。Pico、4個の
DRV8835、外部電源のGNDは共通にします。DRV8835のMODEはGNDへ接続します。

| 軸 | 平面基板 | DRV8835出力 |
|---|---|---|
| X | A+ / A- | AOUT1 / AOUT2 |
| X | B+ / B- | BOUT1 / BOUT2 |
| Y | C+ / C- | AOUT1 / AOUT2 |
| Y | D+ / D- | BOUT1 / BOUT2 |

| 軸 | DRV8835制御入力 | Pico GPIO | Pico物理ピン |
|---|---|---:|---:|
| X | AIN1 | GP19 | 25 |
| X | AIN2 | GP20 | 26 |
| X | BIN1 | GP21 | 27 |
| X | BIN2 | GP22 | 29 |
| Y | AIN1 | GP15 | 20 |
| Y | AIN2 | GP16 | 21 |
| Y | BIN1 | GP17 | 22 |
| Y | BIN2 | GP18 | 24 |

相順はXが`A+ → B- → A- → B+`、Yが`C+ → D- → C- → D+`です。
GP2～GP5は将来のmicroSD用として未使用です。GP12はPWMサーボZに使用します。
GP12はDRV8835出力と異なるPWMスライスなので、50 Hzのサーボ信号を設定してもXYの20 kHz PWMへ影響しません。
GP8～GP11は任意のAS5600二系統I2C、未使用のGP13とGP14は起動時にLowへ固定します。

### 4モジュール制御基板との互換性

`drv8835-control-board/`では1相にAE-DRV8835-Sを1個使い、モジュール内の2個のHブリッジを
並列化しています。各相の`AIN1=BIN1`、`AIN2=BIN2`へ同じGPIO信号を入れ、
`AOUT1=BOUT1`を相の`+`、`AOUT2=BOUT2`を相の`-`へ接続します。これは旧ブレッドボード試験の
論理信号と同じで、専用ファームやピン変更は不要です。MODEはGNDのIN/INモードです。

| 相 | IN1 / IN2 | 出力 | U1正方向の励磁順 |
|---|---|---|---|
| A | GP19 / GP20 | A+ / A- | 1番目、A+ |
| B | GP21 / GP22 | B+ / B- | 2番目、B- |
| C | GP15 / GP16 | C+ / C- | 1番目、C+ |
| D | GP17 / GP18 | D+ / D- | 2番目、D- |

名刺4枚サイズフレキも各相5 mmピッチ、B/D相2.5 mmオフセット、端子順を維持しているため、
`DEFAULT_STEPS_PER_MM=0.4`と相順は変更しません。ただし各相の概算抵抗は約1.25～1.36Ωです。
さらに1.5Ω直列抵抗を入れてVM=3.0 Vとした場合、配線・ドライバ損失を無視しても電流上限は
約1.05～1.09 Aです。旧試作より磁力が不足し、見かけ上の脱調になる可能性があります。

### PWMサーボZ配線

| 信号 | Pico GPIO | Pico物理ピン | 接続 |
|---|---:|---:|---|
| サーボPWM | GP12 | 16 | PWMサーボの信号線 |
| サーボ電源 | - | - | 外部安定化5 V |
| サーボGND | GND | 任意GND | Pico、DRV8835、外部5 Vと共通 |

GP10はDRV8835版では第2 AS5600のI2C1 SDAとして使用します。DYNAMIXEL用ファームとは
同時使用しないため、PWMサーボや現在のDRV8835出力とは競合しません。
サーボをPicoの3V3から給電しないでください。

### AS5600二系統の任意配線

| 関節 | AS5600 SDA | AS5600 SCL | 電源 | 未接続端子 |
|---|---|---|---|---|
| J1 | GP8 / 物理11番 | GP9 / 物理12番 | 3.3 V / GND | OUT、PGO |
| J2 | GP10 / 物理14番 | GP11 / 物理15番 | 3.3 V / GND | OUT、PGO |

`DIR`は初回GNDへ接続します。2個とも同じ`0x36`ですが、J1はI2C0、J2はI2C1なので
アドレスマルチプレクサは不要です。片方または両方を接続しなくてもモータ運転は継続します。
将来のmicroSD用としてGP2～GP5は使用せずに残します。

## 電源と初期値

- DRV8835のVMは3Vから開始する
- 電源電流制限は1.5Aから開始する
- 各相の直列抵抗は1.5Ω、5W以上とする
- マイクロステップ相当分割数は1（単相励磁）
- X/YピークPWMは100%
- 最終移動から500ms後に出力を自動停止する

DRV8835には相電流をmAで設定する機能がないため、`M980`のX/Y値は電流値ではなく
PWM duty上限です。電流はVM、直列抵抗、基板配線抵抗、磁石位置で変化します。

## Z・ペン上下

`G0/G1`のZ値は連続位置補間ではなく、PWMサーボの上下状態へ変換します。既定では
`Z > 0.5`がペン上、それ以外がペン下です。XYを含まないZ命令は`M17`前でも実行できます。

```gcode
M281 U1000 D1800 T150 Z0.5
G0 Z1
G1 Z0
M3 S1400
M3 S1000
M5
```

| 命令 | 意味 |
|---|---|
| `M281 U... D... T... Z...` | 上パルス、下パルス、待機ms、上下判定値を設定 |
| `G0/G1 Z1` | ペン上 |
| `G0/G1 Z0` | ペン下 |
| `M3 S500..2500` | パルス幅usを直接指定。DYNAMIXEL版PlotterFlowとの互換用 |
| `M5` | ペン上 |

`M281`の設定範囲はU/Dが500～2500 us、Tが0～2000 msです。引数なしで現在値を表示します。
設定はFlashへ保存しません。`M18`、ジョグキャンセル、Ctrl-XではXY出力を停止し、ペンも上へ
戻します。一時停止`!`では描画再開を可能にするため、ペン状態を変えません。

## M980設定

```gcode
M980 U8 X60 Y60 I100 J100 H500 C100 B8 R16 A1
```

| 引数 | 範囲 | 意味 |
|---|---:|---|
| U | 1、2、4、8、16 | 2.5mmの1状態を分割する数 |
| X | 1～100 | X軸の通常走行PWM duty（%） |
| Y | 1～100 | Y軸の通常走行PWM duty（%） |
| I | 1～100 | X軸の初動PWM duty（%） |
| J | 1～100 | Y軸の初動PWM duty（%） |
| B | 0～10000 | 初動PWMを維持する軸ごとの実マイクロステップ数 |
| R | 0～10000 | 初動PWMから通常PWMへ線形に戻す軸ごとの実マイクロステップ数 |
| H | 0～5000 | 最終移動後に全出力をLowへ戻すまでの時間（ms） |
| C | 0～500 | 出力開始時に現在の電気角を初動PWMで捕捉する時間（ms） |
| A | 0 / 1 | `A1`は移動軸だけ励磁、`A0`は常にXY両軸を励磁 |

設定変更前には`M18`が必要です。引数なしの`M980`は現在値を表示します。設定はFlashへ
保存されません。`B0 R0`では初動ブーストが無効になり、従来どおりX/Yで指定した通常PWMを
常に使います。従来形式の`M980 U8 X100 Y100 H500 A1`もそのまま使用できます。
`A1`でもXY同時移動では両軸を励磁します。

## 初動ブースト

初動ブーストは、静止摩擦を越えるために移動開始時だけPWM振幅を変えるDRV8835内部機能です。
電気角、cos/sinマイクロステップ、`G0/G1`、`$J`の形式は変更しません。設定後は通常の移動命令へ
自動適用されるため、移動ごとに`M980`や専用移動命令を送る必要はありません。

ブーストは出力OFFまたはHi-Zから動き始める軸と、保持中に新しく励磁対象へ加わった軸だけで
開始します。X/YはBresenham補間で各軸が実際に進んだマイクロステップ数を別々に数えます。
捕捉中と最初の`B`ステップは初動PWMを使い、続く`R`ステップで通常PWMへ線形補間します。
移動完了後の保持出力は通常PWMです。移動が`B + R`より短い場合も軸ごとの進行度を保存し、
出力保持中に同じ軸の次のG1が始まれば、最初からやり直さず残りのブースト遷移を継続します。

出力を保持したまま同じ軸の短い`G1`が連続する場合、線分ごとには再ブーストせず、軸ごとの
実マイクロステップ数を線分間で引き継ぎます。
同じ軸の方向反転も、出力を保持している限り第1段階では再ブーストしません。`H`経過後、`M18`、
ジョグキャンセル、ソフトリセットなどで出力がLowになった後の次の移動では再び適用されます。
`M122`で通常PWM、初動PWM、設定ステップ数、`boost_active_mask`、軸ごとの`boost/run`状態を確認できます。

`I/J100`は常時100%ではなくても、開始時の電流、DRV8835、1.5Ω直列抵抗、電源配線の発熱を
増やします。低いVMと電流制限から短時間で確認してください。この機能はPWM振幅を開ループで
変えるだけで、加減速、初動時の電気角変更、電流測定、電流フィードバック、脱調検知は行いません。

## 最初の確認

VMを切った状態でUF2を書き込み、USBシリアルを115200設定で接続します。

```gcode
M115
M18
M281
M980
M122
```

`M115`に`pico2-gcode-drv8835-xy`、`M122`に`outputs=HiZ`が出ることを確認します。
GP15からGP22の使用ピンがLowであることを確認してから、VMを3V、電流制限1.5Aで投入します。
サーボ電源OFFでGP12が50 Hz、約1000 us High（ペンアップ）になっていることも確認します。

次を1行ずつ送り、X、Y、XYの順に確認します。

```gcode
M18
M980 U8 X60 Y60 I100 J100 H500 C100 B8 R16 A1
M281 U1000 D1800 T150 Z0.5
G0 Z1
M17
G21
G91
G1 X2.5 F300
G1 X-2.5 F300
G1 Y2.5 F300
G1 Y-2.5 F300
G1 X2.5 Y2.5 F300
G1 X-2.5 Y-2.5 F300
G1 Z0
G0 Z1
M122
M18
```

異常な発熱、電源のCC張り付き、配線抵抗の発熱があれば直ちにVMを切ります。`M18`、
ジョグ停止、Ctrl-Xでは全出力を即時Lowへ戻します。通常の線分間は励磁を継続し、最後の
移動から500ms後に自動停止します。

## PlotterFlow

コントローラープロファイルで`Pico 2 DRV8835 XY Planar（開発中）`を選択します。
プロファイルはジョブ開始時に`M18`、`M281`、`M980`、`G0 Z1`、`M17`、`G21`、`G90`、`G10 L20`を送り、
切断時に`M18`を送ります。ジョグは通常の`$J=G91 G21 X... Y... F...`です。
ペン上は`G0 Z1`、ペン下は`G1 Z0`です。DYNAMIXEL用プロファイルは従来どおり
`M3 S1400` / `M3 S1000`を使うため、アクチュエータごとの値を混同しません。

標準G-code試験は`examples/drv8835_xy_standard_gcode.gcode`にあります。円は`G2/G3`ではなく、
PlotterFlowと同じ`G1`線分列で近似します。

## PWM動作しきい値試験

PWM dutyを下げながら四角を周回する試験データを2種類用意しています。

- `examples/drv8835_pwm_threshold_square.gcode`: 各Dutyで10mm角を1周する推奨版
- `examples/drv8835_pwm_two_edges_square.gcode`: 2辺ごとにDutyを5%下げる比較版

推奨版はX正方向、Y正方向、X負方向、Y負方向を同じDutyで確認できるため、Duty差と軸・方向差を
分離しやすくなります。比較版は短時間で傾向を見られますが、各Dutyで2方向しか試さないため、
止まった付近は推奨版で再確認してください。

両方とも100%から40%まで5%刻み、`U1`の1相励磁、`A1`の移動軸のみ励磁、10mm角、
`F300`です。`B0 R0`で初動ブーストを無効にし、`I/J`を`X/Y`と同じ値にしているため、
捕捉時だけ高いDutyが加わることはありません。

`M980`はG-code実行途中でも使用できますが、設定変更前に`M18`が必要です。設定時は物理ステップと
電気角を現在の論理座標における基準相へ同期します。この試験は各Dutyの間で一度出力をLowにし、
500ms待ってから再設定・再捕捉するため、「動き続けられる最低Duty」ではなく
「停止状態から再び捕捉して動き出せる最低Duty」を測ります。静止摩擦を含む実用上の開始条件として
安全側の結果になります。

最初はVMと電流制限を安全な値にして100%の1周だけを手動送信し、正常に戻ることを確認してから
ファイル全体を送信してください。止まったDuty、軸、方向を記録し、その一段上のDutyを実用下限の
候補とします。連続運転値にはさらに5～10ポイントの余裕を持たせてください。

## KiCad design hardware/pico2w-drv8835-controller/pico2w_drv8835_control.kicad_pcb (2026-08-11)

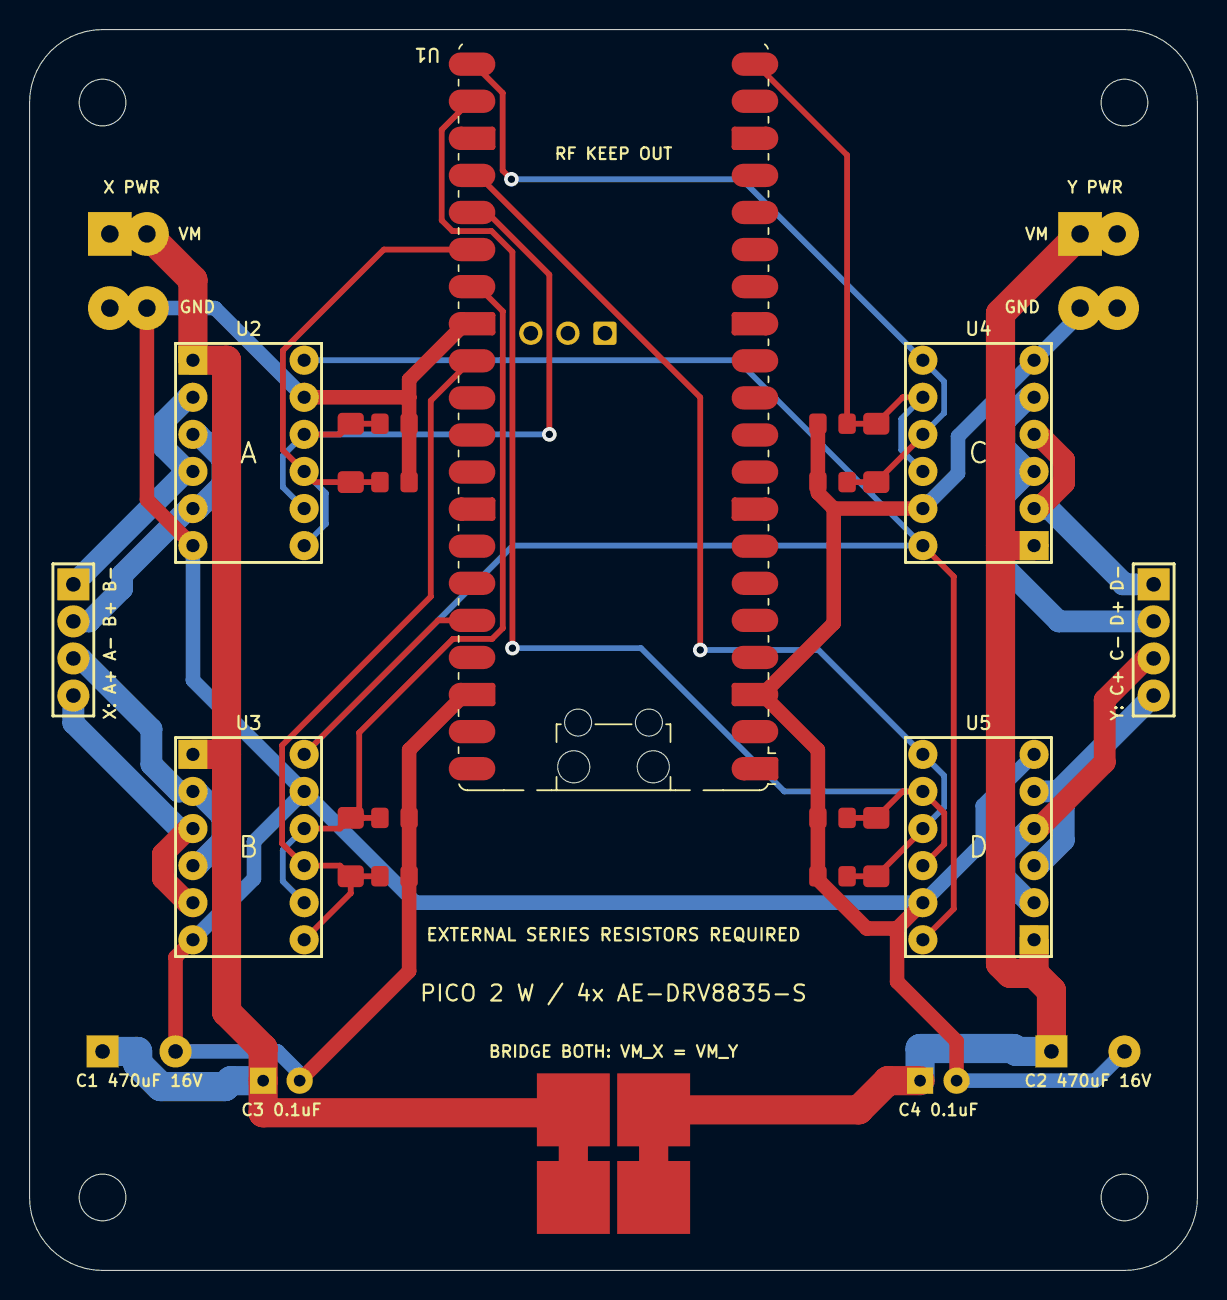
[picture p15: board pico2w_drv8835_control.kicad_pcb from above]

Board: 2 copper layers, 80.0 x 85.0 mm, 35 parts (0 on the bottom side), 20 nets.

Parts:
C1, C2: 470uF 16V
C3, C4: 0.1uF
H1, H2, H3, H4: MountingHole_3.2mm
J1: X POWER SPLIT 2x2
J2: Y POWER SPLIT 2x2
J3: X OUTPUT
J4: Y OUTPUT
R1, R2, R3, R4, R5, R6, R7, R8: 10k PULLDOWN
SJ1, SJ2: VM_X-VM_Y LINK
TP1: A_IN1
TP2: A_IN2
TP3: B_IN1
TP4: B_IN2
TP5: C_IN1
TP6: C_IN2
TP7: D_IN1
TP8: D_IN2
U1: Raspberry Pi Pico 2 W; RaspberryPi_Pico_W_SMD_HandSolder
U2: AE-DRV8835-S PHASE A
U3: AE-DRV8835-S PHASE B
U4: AE-DRV8835-S PHASE C
U5: AE-DRV8835-S PHASE D

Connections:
+3V3: U1.36, U2.12, U3.12, U4.12, U5.12
A+: J3.1, U2.2, U2.4
A-: J3.2, U2.3, U2.5
A_IN1: R1.1, TP1.1, U1.25, U2.8, U2.10
A_IN2: R2.1, TP2.1, U1.26, U2.7, U2.9
B+: J3.3, U3.2, U3.4
B-: J3.4, U3.3, U3.5
B_IN1: R3.1, TP3.1, U1.27, U3.8, U3.10
B_IN2: R4.1, TP4.1, U1.29, U3.7, U3.9
C+: J4.1, U4.2, U4.4
C-: J4.2, U4.3, U4.5
C_IN1: R5.1, TP5.1, U1.20, U4.8, U4.10
C_IN2: R6.1, TP6.1, U1.21, U4.7, U4.9
D+: J4.3, U5.2, U5.4
D-: J4.4, U5.3, U5.5
D_IN1: R7.1, TP7.1, U1.22, U5.8, U5.10
D_IN2: R8.1, TP8.1, U1.24, U5.7, U5.9
GND: C1.2, C2.2, C3.2, C4.2, J1.3, J1.4, J2.3, J2.4, R1.2, R2.2, R3.2, R4.2, R5.2, R6.2, R7.2, R8.2, U1.3, U1.28, U1.38, U2.6, U2.11, U3.6, U3.11, U4.6, U4.11, U5.6, U5.11
VM_X: C1.1, C3.1, J1.1, J1.2, SJ1.1, SJ2.1, U2.1, U3.1
VM_Y: C2.1, C4.1, J2.1, J2.2, SJ1.2, SJ2.2, U4.1, U5.1

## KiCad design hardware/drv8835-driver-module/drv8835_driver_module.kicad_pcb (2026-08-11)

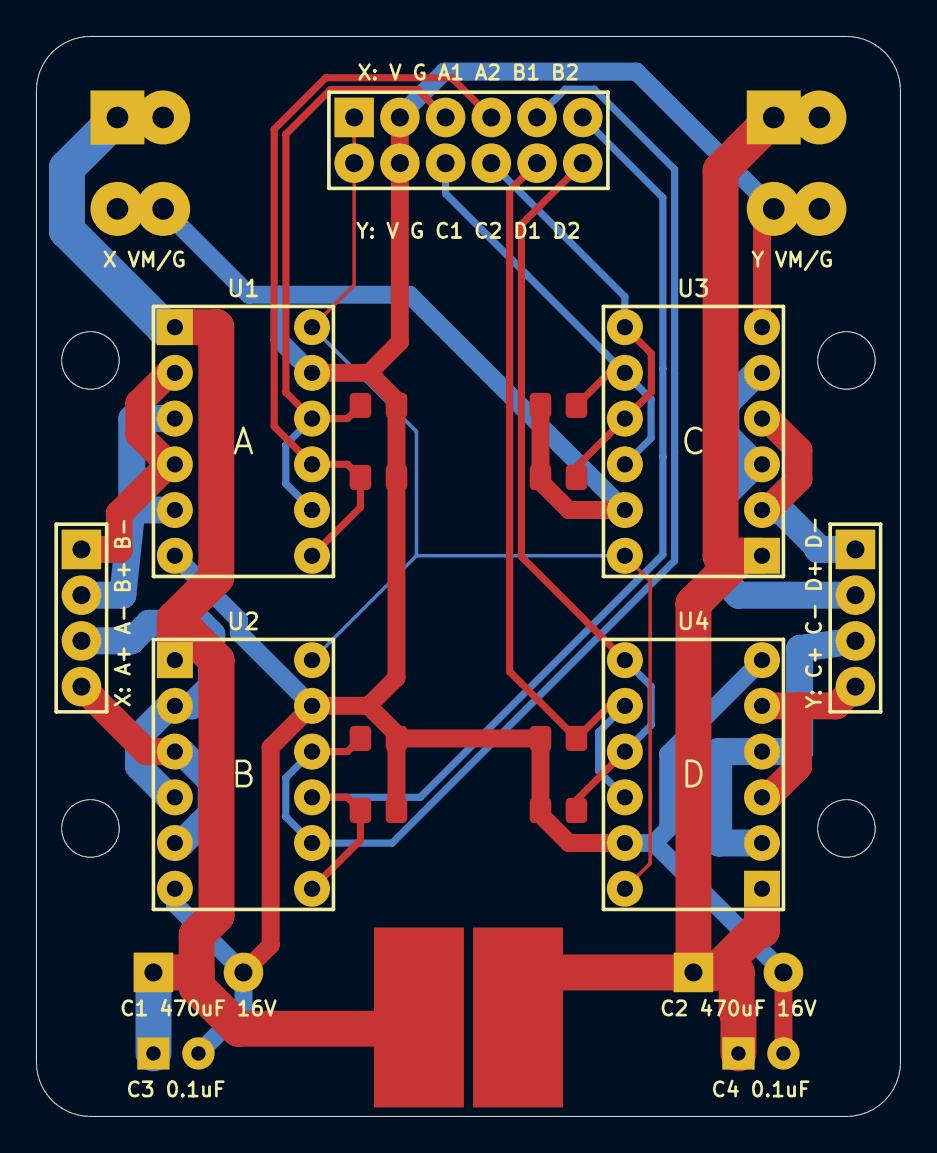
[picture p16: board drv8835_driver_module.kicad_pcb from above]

Board: 2 copper layers, 48.0 x 60.0 mm, 27 parts (0 on the bottom side), 20 nets.

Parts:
C1, C2: 470uF 16V
C3, C4: 0.1uF
H1, H2, H3, H4: MountingHole_3.2mm
J1: MCU INPUT X/Y 2x6
J2: X POWER
J3: Y POWER
J4: X OUTPUT
J5: Y OUTPUT
R1, R2, R3, R4, R5, R6, R7, R8: 10k PULLDOWN
SJ1, SJ2: VM_X-VM_Y LINK
U1: AE-DRV8835-S PHASE A
U2: AE-DRV8835-S PHASE B
U3: AE-DRV8835-S PHASE C
U4: AE-DRV8835-S PHASE D

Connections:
A+: J4.1, U1.2, U1.4
A-: J4.2, U1.3, U1.5
A_IN1: J1.3, R1.1, U1.8, U1.10
A_IN2: J1.4, R2.1, U1.7, U1.9
B+: J4.3, U2.2, U2.4
B-: J4.4, U2.3, U2.5
B_IN1: J1.5, R3.1, U2.8, U2.10
B_IN2: J1.6, R4.1, U2.7, U2.9
C+: J5.1, U3.2, U3.4
C-: J5.2, U3.3, U3.5
C_IN1: J1.9, R5.1, U3.8, U3.10
C_IN2: J1.10, R6.1, U3.7, U3.9
D+: J5.3, U4.2, U4.4
D-: J5.4, U4.3, U4.5
D_IN1: J1.11, R7.1, U4.8, U4.10
D_IN2: J1.12, R8.1, U4.7, U4.9
GND: C1.2, C2.2, C3.2, C4.2, J1.2, J1.8, J2.3, J2.4, J3.3, J3.4, R1.2, R2.2, R3.2, R4.2, R5.2, R6.2, R7.2, R8.2, U1.6, U1.11, U2.6, U2.11, U3.6, U3.11, U4.6, U4.11
VCC: J1.1, J1.7, U1.12, U2.12, U3.12, U4.12
VM_X: C1.1, C3.1, J2.1, J2.2, SJ1.1, SJ2.1, U1.1, U2.1
VM_Y: C2.1, C4.1, J3.1, J3.2, SJ1.2, SJ2.2, U3.1, U4.1

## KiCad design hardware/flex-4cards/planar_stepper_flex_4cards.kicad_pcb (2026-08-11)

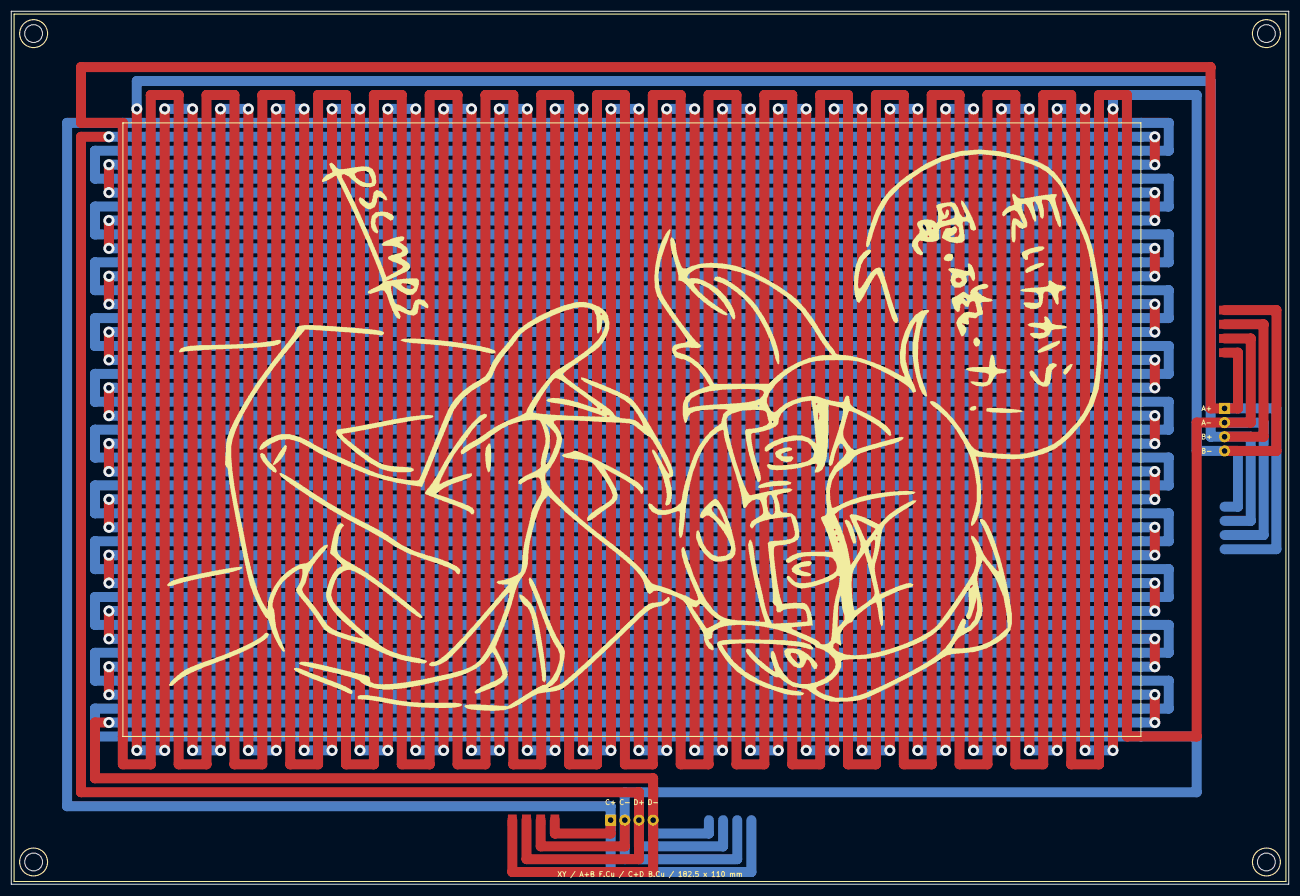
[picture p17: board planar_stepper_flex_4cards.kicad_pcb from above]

Board: 2 copper layers, 229.0 x 156.5 mm, 6 parts (0 on the bottom side), 4 nets.

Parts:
H1, H2, H3, H4: MountingHole_3.2mm
J1, J2: Conn_01x04_Pin_2.54mm

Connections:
COIL_A: J1.1, J1.2
COIL_B: J1.3, J1.4
COIL_C: J2.1, J2.2
COIL_D: J2.3, J2.4

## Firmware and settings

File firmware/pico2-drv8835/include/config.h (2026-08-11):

#pragma once

#include <stdint.h>

#define MOTION_BACKEND_DRV8835 1
#ifndef MOTION_WIFI_AP
#define MOTION_WIFI_AP 0
#endif

#if MOTION_WIFI_AP
#define FW_NAME "pico2w-gcode-drv8835-wifi"
#define FW_VERSION "0.9.3"
#else
#define FW_NAME "pico2-gcode-drv8835-xy"
#define FW_VERSION "0.8.3"
#endif

#define PIN_DRV_X_A_IN1 19u
#define PIN_DRV_X_A_IN2 20u
#define PIN_DRV_X_B_IN1 21u
#define PIN_DRV_X_B_IN2 22u
#define PIN_DRV_Y_C_IN1 15u
#define PIN_DRV_Y_C_IN2 16u
#define PIN_DRV_Y_D_IN1 17u
#define PIN_DRV_Y_D_IN2 18u
#define DRV8835_PWM_FREQUENCY_HZ 20000u
#define DRV8835_DEFAULT_MICROSTEPS 1u
#define DRV8835_DEFAULT_X_PEAK_DUTY 100u
#define DRV8835_DEFAULT_Y_PEAK_DUTY 100u
#define DRV8835_DEFAULT_X_START_PEAK_DUTY DRV8835_DEFAULT_X_PEAK_DUTY
#define DRV8835_DEFAULT_Y_START_PEAK_DUTY DRV8835_DEFAULT_Y_PEAK_DUTY
#define DRV8835_DEFAULT_BOOST_STEPS 0u
#define DRV8835_DEFAULT_BOOST_RAMP_STEPS 0u
#define DRV8835_DEFAULT_HOLD_MS 500u
#define DRV8835_DEFAULT_CAPTURE_MS 100u
#define DRV8835_DEFAULT_ACTIVE_AXES_ONLY 1

#define PIN_PEN_SERVO_PWM 12u
#define SERVO_PEN_PWM_FREQUENCY_HZ 50u
#define SERVO_PEN_DEFAULT_UP_US 1000u
#define SERVO_PEN_DEFAULT_DOWN_US 1800u
#define SERVO_PEN_DEFAULT_SETTLE_MS 150u
#define SERVO_PEN_DEFAULT_Z_THRESHOLD 0.5f

#define PIN_CURRENT_SENSOR_XA_GPIO 26u
#define PIN_CURRENT_SENSOR_XA_ADC_INPUT 0u
#define CURRENT_SENSOR_SENSITIVITY_V_PER_A 0.132f
#define CURRENT_SENSOR_PRESENT_RAW_MIN 1000u
#define CURRENT_SENSOR_PRESENT_RAW_MAX 3100u
#define CURRENT_SENSOR_SAMPLE_INTERVAL_US 1000u
#define CURRENT_SENSOR_REPORT_INTERVAL_MS 100u
#define CURRENT_SENSOR_ZERO_SAMPLES 64u

#define PIN_AS5600_J1_SDA 8u
#define PIN_AS5600_J1_SCL 9u
#define PIN_AS5600_J2_SDA 10u
#define PIN_AS5600_J2_SCL 11u
#define AS5600_I2C_ADDRESS 0x36u
#define AS5600_I2C_FREQUENCY_HZ 400000u
#define AS5600_I2C_TIMEOUT_US 500u
#define AS5600_POLL_INTERVAL_MS 20u

// GP2..5 are intentionally free for a future SPI0 microSD interface.
#define PIN_FUTURE_SD_SCK 2u
#define PIN_FUTURE_SD_MOSI 3u
#define PIN_FUTURE_SD_MISO 4u
#define PIN_FUTURE_SD_CS 5u

#define PIN_CONFLICTS_DRV8835_OR_SERVO(pin) \
    ((pin) == PIN_PEN_SERVO_PWM || (pin) == PIN_DRV_X_A_IN1 || \
     (pin) == PIN_DRV_X_A_IN2 || (pin) == PIN_DRV_X_B_IN1 || \
     (pin) == PIN_DRV_X_B_IN2 || (pin) == PIN_DRV_Y_C_IN1 || \
     (pin) == PIN_DRV_Y_C_IN2 || (pin) == PIN_DRV_Y_D_IN1 || \
     (pin) == PIN_DRV_Y_D_IN2)

#if PIN_CONFLICTS_DRV8835_OR_SERVO(PIN_CURRENT_SENSOR_XA_GPIO)
#error "Current sensor ADC pin conflicts with a DRV8835 or servo output"
#endif
#if PIN_CONFLICTS_DRV8835_OR_SERVO(PIN_AS5600_J1_SDA) || \
    PIN_CONFLICTS_DRV8835_OR_SERVO(PIN_AS5600_J1_SCL) || \
    PIN_CONFLICTS_DRV8835_OR_SERVO(PIN_AS5600_J2_SDA) || \
    PIN_CONFLICTS_DRV8835_OR_SERVO(PIN_AS5600_J2_SCL)
#error "AS5600 I2C pins conflict with a DRV8835 or servo output"
#endif

// Four full electrical states cover the 10 mm field period.
#define DEFAULT_STEPS_PER_MM 0.4f
#define DEFAULT_FEED_MM_MIN 500.0f
#define DEFAULT_JOG_FEED_MM_MIN 1000.0f
#define DEFAULT_MICROSTEPS 1

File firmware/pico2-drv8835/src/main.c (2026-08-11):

#include <stdio.h>
#include <string.h>

#include "pico/stdlib.h"

#include "config.h"
#include "gcode.h"
#include "planner.h"
#if MOTION_BACKEND_DRV8835
#include "current_monitor.h"
#include "position_sensors.h"
#include "servo_pen.h"
#endif
#include "stepper.h"

static void print_banner(void) {
    printf("\r\n%s %s ready\r\n", FW_NAME, FW_VERSION);
    printf("[MSG:'$' not implemented; PlotterFlow GRBL/FluidNC subset active]\r\n");
}

int main(void) {
    stepper_safe_init();
#if MOTION_BACKEND_DRV8835
    servo_pen_safe_init();
    current_monitor_init();
    position_sensors_init();
#endif
    stdio_init_all();
    sleep_ms(1200);

    print_banner();
#if MOTION_BACKEND_DRV8835
    printf("[SAFE: DRV8835 IN/IN initialized LOW before USB startup]\r\n");
    printf("[SAFE: pen servo GP%u initialized UP at %uus]\r\n",
           PIN_PEN_SERVO_PWM, servo_pen_current_pulse_us());
#else
    printf("[SAFE: X/Y EN initialized HIGH (disabled) before USB startup]\r\n");
#endif

    controller_state_t state;
    gcode_state_init(&state);
    planner_init();
#if !MOTION_BACKEND_DRV8835
    tmc2209_bus_init();
    const bool x_ready = tmc2209_init_driver(TMC_ADDR_X, DEFAULT_X_RUN_CURRENT_MA,
                                             DEFAULT_X_HOLD_CURRENT_MA, DEFAULT_MICROSTEPS);
    const bool y_ready = tmc2209_init_driver(TMC_ADDR_Y, DEFAULT_Y_RUN_CURRENT_MA,
                                             DEFAULT_Y_HOLD_CURRENT_MA, DEFAULT_MICROSTEPS);
    printf("[TMC INIT: X=%s Y=%s; EN remains disabled until M17/motion]\r\n",
           x_ready ? "ok" : "failed", y_ready ? "ok" : "failed");
#else
    printf("[DRV8835 INIT: X=GP19/20/21/22 Y=GP15/16/17/18 "
           "Z_SERVO=GP%u; outputs remain HiZ until motion]\r\n",
           PIN_PEN_SERVO_PWM);
    printf("[CURRENT INIT: optional X-A sensor=GP%u/ADC%u; "
           "missing sensor does not block motion]\r\n",
           PIN_CURRENT_SENSOR_XA_GPIO, PIN_CURRENT_SENSOR_XA_ADC_INPUT);
    printf("[POSITION INIT: optional AS5600 J1=I2C0 GP%u/GP%u "
           "J2=I2C1 GP%u/GP%u; missing sensors do not block motion]\r\n",
           PIN_AS5600_J1_SDA, PIN_AS5600_J1_SCL,
           PIN_AS5600_J2_SDA, PIN_AS5600_J2_SCL);
#endif

    char line[160];
    size_t length = 0;

    while (true) {
        int ch = getchar_timeout_us(1000);
        if (ch == PICO_ERROR_TIMEOUT) {
            planner_service();
            continue;
        }

        if (ch == '?' || ch == '!' || ch == '~' || ch == 0x18 || ch == 0x85) {
            gcode_process_realtime(ch, &state);
            continue;
        }

        if (ch == '\r' || ch == '\n') {
            if (length > 0) {
                line[length] = '\0';
                gcode_process_line(line, &state);
                length = 0;
            }
            continue;
        }

        if (length < sizeof(line) - 1) {
            line[length++] = (char)ch;
        } else {
            length = 0;
            printf("error: line too long\r\n");
        }
    }
}

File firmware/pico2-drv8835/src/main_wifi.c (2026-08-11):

#include <stdio.h>

#include "pico/stdlib.h"

#include "config.h"
#include "current_monitor.h"
#include "gcode.h"
#include "planner.h"
#include "position_sensors.h"
#include "servo_pen.h"
#include "stepper.h"
#include "wifi_control.h"

static void print_banner(void) {
    printf("\r\n%s %s ready\r\n", FW_NAME, FW_VERSION);
    printf("[SAFE: DRV8835 GP15..22 initialized LOW before USB/Wi-Fi startup]\r\n");
}

static void service_wifi(controller_state_t *state) {
    static uint32_t next_client_check_ms = 0;
    static int previous_client_count = -1;
    if (wifi_control_take_stop()) {
        planner_cancel_jog(state);
        char pen_up_command[] = "G0 Z1";
        gcode_process_line(pen_up_command, state);
        wifi_control_set_result("stopped");
        printf("[MSG:Wi-Fi stop; DRV8835 outputs HiZ; pen up]\r\n");
    }

    bool pen_up = false;
    if (wifi_control_take_pen(&pen_up)) {
        char pen_command[16];
        snprintf(pen_command, sizeof(pen_command),
                 pen_up ? "G0 Z1" : "G1 Z0");
        wifi_control_set_running();
        gcode_process_line(pen_command, state);
        wifi_control_set_result(pen_up ? "pen_up" : "pen_down");
    }

    wifi_drive_request_t drive_request;
    if (wifi_control_take_mode(&drive_request)) {
        char disable_command[] = "M18";
        char mode_command[48];
        snprintf(mode_command, sizeof(mode_command), "M980 U%u A%u C%u",
                 drive_request.microsteps,
                 drive_request.active_axes_only ? 1u : 0u,
                 drive_request.capture_ms);
        gcode_process_line(disable_command, state);
        gcode_process_line(mode_command, state);
        wifi_control_set_result("configured");
    }

    wifi_jog_request_t request;
    if (wifi_control_take_jog(&request)) {
        char command[64];
        const int length = wifi_jog_build_gcode(&request, command, sizeof(command));
        if (length <= 0 || (size_t)length >= sizeof(command)) {
            wifi_control_set_result("error");
        } else {
            wifi_control_set_running();
            printf("[MSG:Wi-Fi jog %s]\r\n", command);
            gcode_process_line(command, state);
            if (wifi_control_take_stop()) {
                planner_cancel_jog(state);
                wifi_control_set_result("stopped");
            } else {
                wifi_control_set_result("ok");
            }
        }
    }
    planner_service();
    wifi_control_update_status(state);

    const uint32_t now_ms = to_ms_since_boot(get_absolute_time());
    if ((int32_t)(now_ms - next_client_check_ms) >= 0) {
        const int clients = wifi_control_ap_client_count();
        if (clients >= 0 && clients != previous_client_count) {
            printf("[WIFI AP: clients=%d]\r\n", clients);
            previous_client_count = clients;
        }
        next_client_check_ms = now_ms + 1000u;
    }
}

int main(void) {
    stepper_safe_init();
    servo_pen_safe_init();
    current_monitor_init();
    position_sensors_init();
    stdio_init_all();
    sleep_ms(1200);
    print_banner();

    controller_state_t state;
    gcode_state_init(&state);
    planner_init();
    printf("[DRV8835 INIT: X=GP19/20/21/22 Y=GP15/16/17/18 "
           "Z_SERVO=GP%u UP=%uus; outputs HiZ]\r\n",
           PIN_PEN_SERVO_PWM, servo_pen_current_pulse_us());
    printf("[CURRENT INIT: optional X-A sensor=GP%u/ADC%u; "
           "missing sensor does not block motion]\r\n",
           PIN_CURRENT_SENSOR_XA_GPIO, PIN_CURRENT_SENSOR_XA_ADC_INPUT);
    printf("[POSITION INIT: optional AS5600 J1=I2C0 GP%u/GP%u "
           "J2=I2C1 GP%u/GP%u; missing sensors do not block motion]\r\n",
           PIN_AS5600_J1_SDA, PIN_AS5600_J1_SCL,
           PIN_AS5600_J2_SDA, PIN_AS5600_J2_SCL);

    if (wifi_control_init()) {
        printf("[WIFI AP: SSID=%s password=planar-stepper URL=http://192.168.4.1/]\r\n",
               wifi_control_ssid());
    } else {
        printf("[WIFI ERROR: AP unavailable; USB G-code remains available]\r\n");
    }
    wifi_control_update_status(&state);

    char line[160];
    size_t length = 0;
    while (true) {
        service_wifi(&state);
        const int ch = getchar_timeout_us(1000);
        if (ch == PICO_ERROR_TIMEOUT) {
            continue;
        }
        if (ch == '?' || ch == '!' || ch == '~' || ch == 0x18 || ch == 0x85) {
            gcode_process_realtime(ch, &state);
            continue;
        }
        if (ch == '\r' || ch == '\n') {
            if (length > 0u) {
                line[length] = '\0';
                gcode_process_line(line, &state);
                length = 0u;
            }
            continue;
        }
        if (length < sizeof(line) - 1u) {
            line[length++] = (char)ch;
        } else {
            length = 0u;
            printf("error: line too long\r\n");
        }
    }
}

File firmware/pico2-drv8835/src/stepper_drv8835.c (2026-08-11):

#include "stepper.h"

#include <math.h>
#include <stdio.h>
#include <stdlib.h>

#include "hardware/clocks.h"
#include "hardware/gpio.h"
#include "hardware/pwm.h"
#include "pico/stdlib.h"

#include "config.h"
#include "drv8835_motion_math.h"

#define PWM_COUNTER_HZ 10000000u
#define PWM_WRAP ((PWM_COUNTER_HZ / DRV8835_PWM_FREQUENCY_HZ) - 1u)

enum {
    AXIS_X = 0,
    AXIS_Y = 1,
    AXIS_COUNT = 2,
};

static const unsigned int positive_pins[AXIS_COUNT][2] = {
    {PIN_DRV_X_A_IN1, PIN_DRV_X_B_IN1},
    {PIN_DRV_Y_C_IN1, PIN_DRV_Y_D_IN1},
};

static const unsigned int negative_pins[AXIS_COUNT][2] = {
    {PIN_DRV_X_A_IN2, PIN_DRV_X_B_IN2},
    {PIN_DRV_Y_C_IN2, PIN_DRV_Y_D_IN2},
};

static const unsigned int driver_pins[] = {
    PIN_DRV_X_A_IN1, PIN_DRV_X_A_IN2, PIN_DRV_X_B_IN1, PIN_DRV_X_B_IN2,
    PIN_DRV_Y_C_IN1, PIN_DRV_Y_C_IN2, PIN_DRV_Y_D_IN1, PIN_DRV_Y_D_IN2,
};

static unsigned int microsteps = DRV8835_DEFAULT_MICROSTEPS;
static unsigned int run_peak_duty[AXIS_COUNT] = {
    DRV8835_DEFAULT_X_PEAK_DUTY,
    DRV8835_DEFAULT_Y_PEAK_DUTY,
};
static unsigned int start_peak_duty[AXIS_COUNT] = {
    DRV8835_DEFAULT_X_START_PEAK_DUTY,
    DRV8835_DEFAULT_Y_START_PEAK_DUTY,
};
static unsigned int applied_peak_duty[AXIS_COUNT] = {
    DRV8835_DEFAULT_X_PEAK_DUTY,
    DRV8835_DEFAULT_Y_PEAK_DUTY,
};
static unsigned int boost_steps = DRV8835_DEFAULT_BOOST_STEPS;
static unsigned int boost_ramp_steps = DRV8835_DEFAULT_BOOST_RAMP_STEPS;
static unsigned int boost_axis_step_index[AXIS_COUNT] = {0u, 0u};
static unsigned int boost_active_mask = 0u;
static unsigned int hold_ms = DRV8835_DEFAULT_HOLD_MS;
static unsigned int capture_ms = DRV8835_DEFAULT_CAPTURE_MS;
static bool active_axes_only = DRV8835_DEFAULT_ACTIVE_AXES_ONLY != 0;
static unsigned int active_axis_mask = 0u;
static bool armed = false;
static bool outputs_active = false;
static int angle[AXIS_COUNT] = {0, 0};
static int coil_duty[AXIS_COUNT][2] = {{0, 0}, {0, 0}};
static long physical_step[AXIS_COUNT] = {0, 0};
static float coordinate_origin[AXIS_COUNT] = {0.0f, 0.0f};
static float commanded_position[AXIS_COUNT] = {0.0f, 0.0f};
static absolute_time_t release_deadline;

static const char *phase_name(unsigned int axis, int electrical_angle) {
    static const char *const phase_names[AXIS_COUNT][4] = {
        {"A+", "B-", "A-", "B+"},
        {"C+", "D-", "C-", "D+"},
    };
    const unsigned int phase = (unsigned int)(
        drv8835_wrap_angle(electrical_angle + DRV8835_QUADRANT_UNITS / 2) /
        DRV8835_QUADRANT_UNITS) % 4u;
    return phase_names[axis][phase];
}

static float effective_steps_per_mm(void) {
    return DEFAULT_STEPS_PER_MM * (float)microsteps;
}

static void set_all_pins_low(void) {
    for (size_t i = 0; i < sizeof(driver_pins) / sizeof(driver_pins[0]); i++) {
        const unsigned int pin = driver_pins[i];
        gpio_set_function(pin, GPIO_FUNC_SIO);
        gpio_set_dir(pin, GPIO_OUT);
        gpio_put(pin, 0);
    }
}

static void all_off(void) {
    set_all_pins_low();
    outputs_active = false;
    coil_duty[AXIS_X][0] = 0;
    coil_duty[AXIS_X][1] = 0;
    coil_duty[AXIS_Y][0] = 0;
    coil_duty[AXIS_Y][1] = 0;
    active_axis_mask = 0u;
    boost_active_mask = 0u;
    for (unsigned int axis = 0u; axis < AXIS_COUNT; axis++) {
        boost_axis_step_index[axis] = 0u;
        applied_peak_duty[axis] = run_peak_duty[axis];
    }
}

static void set_pin_duty(unsigned int pin, unsigned int duty_percent) {
    if (duty_percent == 0u) {
        return;
    }
    if (duty_percent >= 100u) {
        gpio_set_function(pin, GPIO_FUNC_SIO);
        gpio_set_dir(pin, GPIO_OUT);
        gpio_put(pin, 1);
        return;
    }
    const uint32_t level =
        ((uint32_t)(PWM_WRAP + 1u) * duty_percent + 99u) / 100u;
    pwm_set_gpio_level(pin, level);
    gpio_set_function(pin, GPIO_FUNC_PWM);
}

static void apply_axis(unsigned int axis) {
    drv8835_axis_duties(angle[axis], applied_peak_duty[axis],
                        &coil_duty[axis][0], &coil_duty[axis][1]);
    for (unsigned int coil = 0; coil < 2u; coil++) {
        const int duty = coil_duty[axis][coil];
        const unsigned int pin = duty >= 0 ? positive_pins[axis][coil]
                                           : negative_pins[axis][coil];
        set_pin_duty(pin, (unsigned int)abs(duty));
    }
}

static void prepare_motion_boost(unsigned int next_active_mask,
                                 unsigned int newly_energized_mask) {
    /* Preserve progress across consecutive blocks on an already held axis. */
    boost_active_mask &= next_active_mask;
    for (unsigned int axis = 0u; axis < AXIS_COUNT; axis++) {
        const unsigned int axis_bit = 1u << axis;
        applied_peak_duty[axis] = run_peak_duty[axis];
        if ((next_active_mask & axis_bit) == 0u) {
            boost_axis_step_index[axis] = 0u;
            boost_active_mask &= ~axis_bit;
        } else if ((newly_energized_mask & axis_bit) != 0u &&
            drv8835_boost_enabled(run_peak_duty[axis],
                                  start_peak_duty[axis], boost_steps,
                                  boost_ramp_steps)) {
            boost_axis_step_index[axis] = 0u;
            applied_peak_duty[axis] = start_peak_duty[axis];
            boost_active_mask |= axis_bit;
        } else if ((newly_energized_mask & axis_bit) != 0u) {
            boost_axis_step_index[axis] = 0u;
            boost_active_mask &= ~axis_bit;
        }
    }
}

static bool prepare_axis_step(unsigned int axis) {
    const unsigned int axis_bit = 1u << axis;
    if ((boost_active_mask & axis_bit) == 0u) {
        applied_peak_duty[axis] = run_peak_duty[axis];
        return false;
    }
    applied_peak_duty[axis] = drv8835_boost_duty_for_step(
        run_peak_duty[axis], start_peak_duty[axis], boost_steps,
        boost_ramp_steps, boost_axis_step_index[axis]);
    boost_axis_step_index[axis]++;
    return boost_axis_step_index[axis] >= boost_steps + boost_ramp_steps;
}

static void apply_outputs(void) {
    set_all_pins_low();
    for (unsigned int axis = 0; axis < AXIS_COUNT; axis++) {
        if ((active_axis_mask & (1u << axis)) != 0u) {
            apply_axis(axis);
        } else {
            coil_duty[axis][0] = 0;
            coil_duty[axis][1] = 0;
        }
    }
    outputs_active = active_axis_mask != 0u;
    sleep_us(10);
}

static void schedule_release(void) {
    if (hold_ms == 0u) {
        all_off();
    } else {
        release_deadline = make_timeout_time_ms(hold_ms);
    }
}
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

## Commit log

2026-08-11 Initial private release candidate
    [bom.csv, drv8835_driver_module.kicad_pcb, one_axis_stepper.kicad_pcb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]
2026-08-11 docs: clarify upstream Raspberry Pi copyright text
2026-08-16 Add PCB stepper motor reference link
    Added a new reference link for PCB stepper motor.
2026-08-16 Update PCB stepper motor reference link
2026-11-09 CLAUDE.md を追加（AGENTS.md を読み込むだけ）
